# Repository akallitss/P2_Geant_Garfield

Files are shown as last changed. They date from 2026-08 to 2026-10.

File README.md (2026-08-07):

# P2 Micromegas Simulation

Geant4 simulation of the P2 wedge Micromegas detector (MESA / Mainz).

> **Read [`docs/HANDOFF.md`](docs/HANDOFF.md) first.**
>
> **Running it on lxplus: [`docs/RUNBOOK.md`](docs/RUNBOOK.md)** — including
> what is *not* yet runnable (Stage B does not exist, there is no pillar
> code, and HTCondor submission does not speak `p2` mode).
>
> **Update 2026-08-06: VMM analysis re-scoped for a *pad* detector, and a
> first time-resolution prediction exists.** The charge cloud fires **~1.1
> pads on average**, so inter-pad clustering is a ~10 % minority effect;
> **VMM neighbor logic** — a strip-detector feature — reads *chip-channel*
> neighbors, which on this pad plane are physical neighbors only 74 % of the
> time in one mapping revision and **7.7 %** in the other (median partner
> distance 12 mm vs **126 mm**). Baseline is therefore **NL off**, with
> clustering done offline on geometric adjacency
> ([`vmm/nl_map.py`](vmm/nl_map.py)). Separately, we now predict a per-pad
> time resolution of **≈ 10–13 ns (Ar mixes) / 15–25 ns (Ne mixes)**,
> dominated entirely by primary-ionization statistics — the number to compare
> against the SPS run
> ([`docs/research/TIME_RESOLUTION_NOTES.md`](docs/research/TIME_RESOLUTION_NOTES.md),
> [`vmm/time_resolution.py`](vmm/time_resolution.py)). Also corrected: the
> "two mapping revisions disagree on 79/1280 pads" claim was a rounding
> artifact — the pad planes are identical to 2.5 µm; the revisions disagree
> on the **readout order** (11/1280 channels agree), which is what matters.
>
> **Update 2026-08-05 (night): it builds and runs.** First working P2
> simulation on lxplus — geometry passes overlap checks, and three bugs were
> fixed getting there (two fatal: self-intersecting `WedgeOutline` polygons
> that killed `G4ExtrudedSolid`, and a ROOT thread-safety race that
> core-dumped every multi-threaded run). Output now carries **full
> provenance**: every gas cluster knows the process, layer, position and
> energy of the interaction that started its chain, and every volume that
> receives energy is scored. The **P0.1 gas-composition bug is fixed** too (volume-vs-mass
> fractions *and* STP-vs-20 °C densities — see
> [`docs/research/GAS_FIX_NOTES.md`](docs/research/GAS_FIX_NOTES.md)).
> First physics, measured with the corrected gas: **90 % of photon-induced
> gas signals originate in the mesh and the copper pad plane**, not in the
> gas, and switching argon → neon removes only **(12 ± 3) %** of them —
> confirming the analysis below. Speed and
> campaign cost: [`docs/BENCHMARKS.md`](docs/BENCHMARKS.md). Biggest
> remaining unknown: [`docs/NEEDED_INPUTS.md`](docs/NEEDED_INPUTS.md).
>
> **Update 2026-08-05 (late): the gas premise changed.** The expected photon
> background is **50–100 keV** (plus a harder tail), well above the Ar
> K-edge. An analytic pass
> ([`docs/research/PHOTON_DISCRIMINATION_NOTES.md`](docs/research/PHOTON_DISCRIMINATION_NOTES.md),
> reproducible via `python3 scripts/photon_budget.py`) finds that (a) Ar vs
> Ne interaction probability differs by only 5.4×→2.1× across the band, and
> (b) **conversions in the mesh and copper pad plane outnumber gas
> conversions by 15–65×**, a gas-independent floor. Net: Ar/Iso and Ne/Iso
> total fake sources differ by under 10 %, while neon costs a 30× worse
> zero-cluster floor — so **argon is now a co-baseline, not the incumbent to
> beat**. The **energy-deposition discrimination** handle (MIP Landau vs
> Compton/photoelectric deposits) is real at 3–30× MIP but its target is the
> minority population. Campaign plan amended throughout; new Phase-0 items
> P0.12 (per-event interaction classification), P0.13 (mesh cross-check)
> and a γ-production-cut bug suppressing Cu-K fluorescence — **all three
> now implemented and verified, see the update above.**
>
> **Update 2026-08-05 (evening):** the simulation **campaign is now planned**
> — [`docs/SIM_CAMPAIGN_PLAN.md`](docs/SIM_CAMPAIGN_PLAN.md) is the working
> document (phases, run matrices, gas candidate list, chain architecture),
> backed by two sourced research notes in
> [`docs/research/`](docs/research/). The **VMM3a electronics emulator is
> implemented and unit-tested** in [`vmm/`](vmm/README.md). Execution is
> **gated on Alexandra's geometry review**; the plan's Phase 0 lists prep
> tasks that are safe now — first among them the **gas-mixture
> mass/volume-fraction bug fix (P0.1)**, which must land before any Ar-vs-Ne
> comparison.
>
> **Update 2026-08-05:** the P2 wedge geometry is now implemented as a new
> `p2` mode (the default) — full stack in gerber coordinates: readout PCB
> (18 µm Cu / 200 µm FR4 / 18 µm Cu), amp gap, woven mesh (48/19 µm, as an
> effective-density slab), drift gap, two-foil drift cathode (1 mm apart, Al
> on the gas side), gas frame, carbon back frame (1 mm) and mylar sheets with
> the overpressure bulge of the outer two modelled as terraced domes.
> **Several dimensions are still educated guesses —
> [`docs/P2_MODEL.md`](docs/P2_MODEL.md) is the list of what is measured vs.
> assumed and what to confirm.** Not yet compiled or validated on lxplus.
> The other modes are inherited MX17 and untouched.

## Layout

| Path | What |
|---|---|
| `mm_sim.cc`, `src/`, `include/` | Geant4 application — `p2` mode (default) + inherited MX17 modes |
| `scripts/model/` | Python mirror of the P2 geometry + figure generation |
| `docs/SIM_CAMPAIGN_PLAN.md` | **THE campaign plan**: phases P0–4, run matrices, gas list, chain architecture, bookkeeping |
| `docs/research/` | sourced research notes: `TOOLCHAIN_NOTES.md` (Geant4/Garfield++/Magboltz/Heed/VMM), `GAS_NOTES.md` (Ne mixtures, flammability, procurement), **`PHOTON_DISCRIMINATION_NOTES.md` (50–100 keV cross-sections, edep discrimination, wall-conversion floor, edep→ADC proportionality)**, `TIMING_PSD_NOTES.md` (time-structure handle), **`TIME_RESOLUTION_NOTES.md` (predicted σ_t per pad, contribution budget, SPS comparison protocol)** |
| `scripts/photon_budget.py` | analytic photon-interaction budget — the numbers the Geant4 photon runs must reproduce |
| `docs/NEEDED_INPUTS.md` | **register of what we are guessing** — spatial/angular distributions, spectra, geometry, noise |
| `docs/BENCHMARKS.md` | measured speed on lxplus + campaign cost estimate |
| `docs/OUTPUT_FORMAT.md` | ROOT/CSV schema: EventTree, ClusterTree provenance, VolumeTree |
| `vmm/` | **VMM3a electronics emulator** (Athena shaper port + pad digitizer, unit-tested), **pad/channel adjacency map (`nl_map.py`)** and the **time-resolution toy (`time_resolution.py`)** — see `vmm/README.md` |
| `docs/P2_MODEL.md` | **as-built model, assumptions, open questions** |
| `docs/P2_EXPERIMENT.md` | P2@MESA / BASKET physics context, kinematics, rates (sourced) |
| `docs/SIM_CAMPAIGN_BRIEF.md` | campaign handoff snapshot (capabilities/assumptions; plan now in SIM_CAMPAIGN_PLAN.md) |
| `macros/`, `scripts/`, `ls_calibration/`, `sr90_calibration/` | build, HTCondor submission and analysis, inherited from MX17 |
| `design/` | P2 fabrication data: gerbers, drill, bulk masks, channel mapping, drift frame — see [`design/README.md`](design/README.md) |
| `scripts/gerber/` | gerber parsing and geometry extraction tools |
| `docs/P2_GEOMETRY.md` | **every P2 dimension, with its source** |
| `docs/HANDOFF.md` | state of play, plan, and open questions |
| `docs/MX17_README.md` | the original MX17 README (modes, CLI, output format) |

## The detector in one table

Measured from the fabrication files (see `docs/P2_GEOMETRY.md`):

| | |
|---|---|
| Shape | 60° annular sector, apex on the beam axis |
| Board | r = 95 → 650 mm, radial edges offset +10 mm, top cut at y = 540 mm |
| Active area | r = 120 → 590 mm, φ = 0.97° → 59.0°, ≈ 1689 cm² |
| Readout | 1280 pads = 10 connectors × 128 ch; 42 rings, 11.43 mm radial pitch |
| Pad cell | ≈ 11.43 × 11.86 mm (area-equalized) |
| Pillars | Ø0.5 mm on a 2.000 mm pitch, 41 366 of them |
| Readout PCB | 2-layer, 0.236 mm (18 µm Cu / 200 µm FR4 / 18 µm Cu) |
| Drift gap | 3 mm confirmed baseline (campaign scans 1–4 mm; two frame variants exist) |

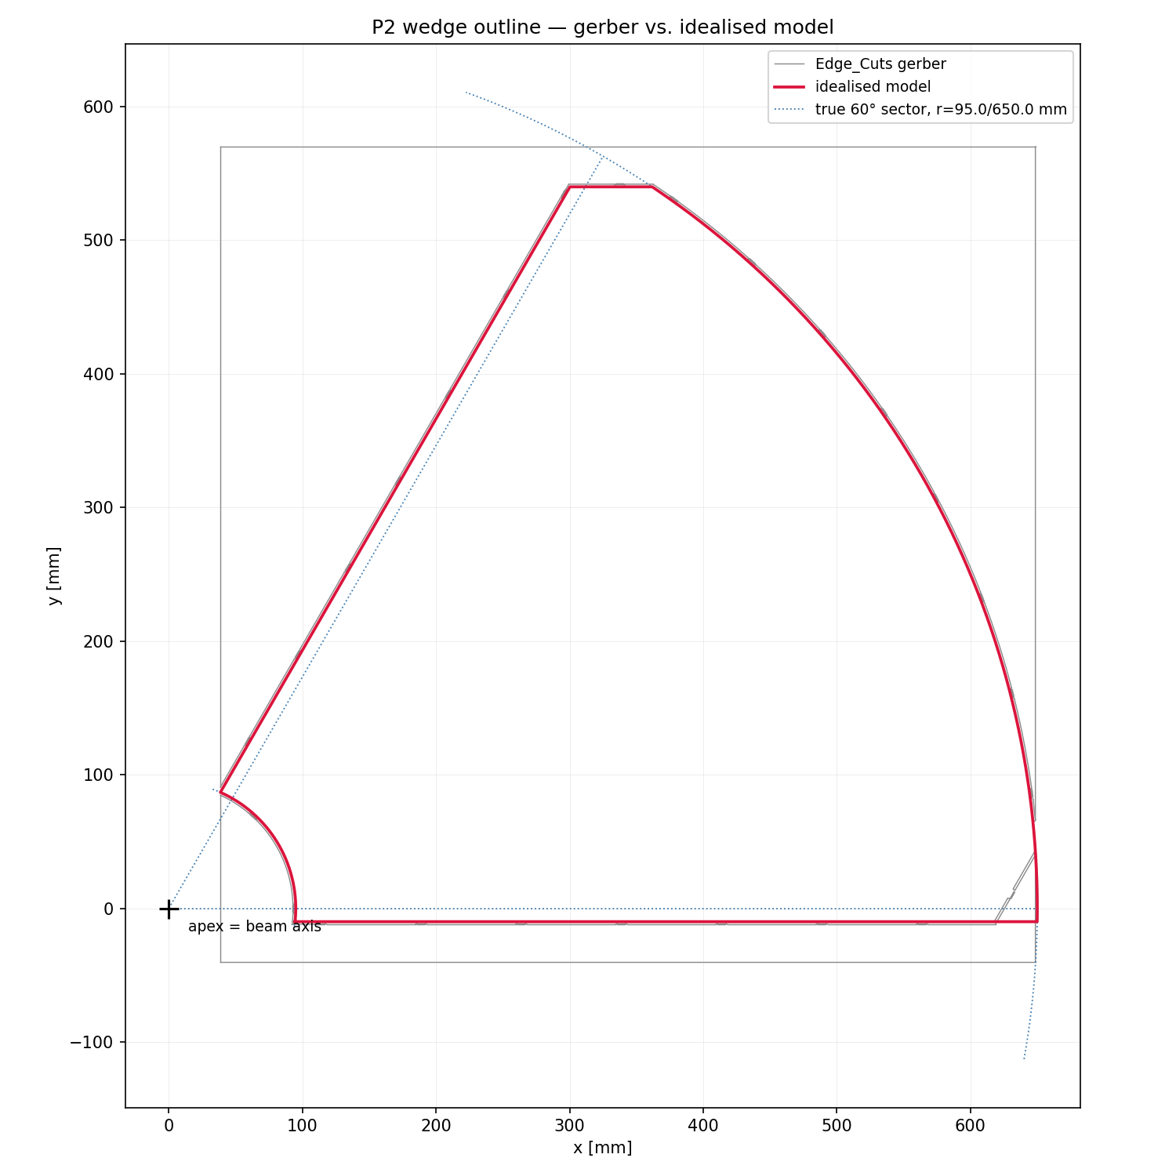
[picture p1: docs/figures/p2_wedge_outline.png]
P2 wedge outline


## Running the P2 simulation

```bash
./build/mm_sim -n 10000                     # p2 mode, ArIso, 155 MeV e-, aimed mid-wedge
./build/mm_sim --drift-gap 4 -g ArCO2       # 4 mm frame variant, different gas
./build/mm_sim --gun-x 150 --gun-y 30       # aim near the inner radius
python scripts/model/plot_p2_model.py       # geometry figures -> docs/figures/
```

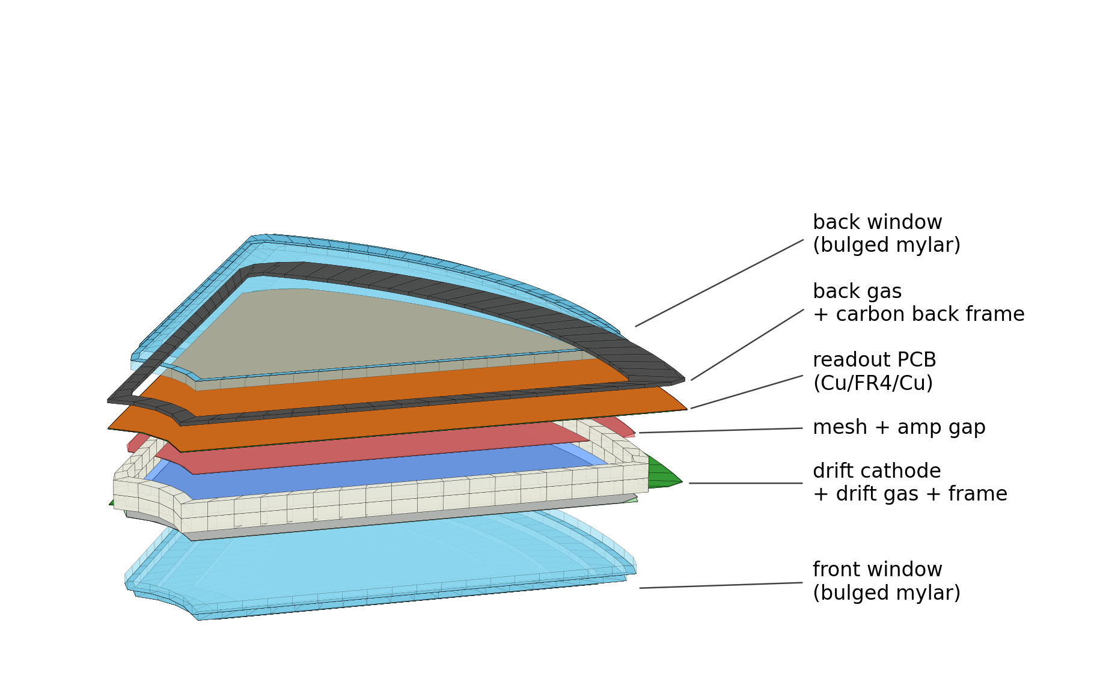
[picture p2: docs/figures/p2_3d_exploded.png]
exploded model


## Gerber tools

```bash
# wedge outline parameters + comparison figure against the gerber
python scripts/gerber/p2_wedge_model.py --out wedge.png

# readout pad map (also cross-checks the two mapping revisions)
python scripts/gerber/analyze_p2_readout.py --plot padmap.png

# full geometry dump for any gerber set
python scripts/gerber/analyze_p2_geometry.py
python scripts/gerber/analyze_p2_geometry.py --dir design/gerbers/RKP2_10x10/Gerber
```

`scripts/gerber/gerber_outline.py` is a small standalone RS-274X reader (no
external gerber library needed); the analysis scripts need numpy and matplotlib.

## Building (inherited from MX17, unchanged)

```bash
source scripts/setup_lxplus.sh   # Geant4 11.2 + ROOT 6.30 from CVMFS
bash scripts/build.sh            # -> build/mm_sim
```

The command-line interface, simulation modes and output format are documented in
[`docs/MX17_README.md`](docs/MX17_README.md) and still apply to the code as it
stands.

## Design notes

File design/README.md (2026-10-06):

# P2 detector design data

Copied 2026-08-05 from
`/media/dylan/LaCie/Extras/Physics/Post-Doc-Saclay/P2-detector-design/`.
Dates below are the ones written *inside* the files, which do not always match
the directory names on the drive (`Version-Nov-25` holds March 2024 output;
`Version_Apr26` holds both January and May 2026 output).

Measurements taken from these files are in [`../docs/P2_GEOMETRY.md`](../docs/P2_GEOMETRY.md).

## `gerbers/P2_BASKET_Apr26/` — current production readout ★

KiCad 9.0.2, generated 2026-01-20, project `P2_BASKET`.
From `wedge_det_design/Version_Apr26/FABRICATION_P2/`.

```
Gerber/     F_Cu, B_Cu, Edge_Cuts, F_ENIG_Finition, User_Drawings
NCDrill/    P2_BASKET.drl + drl_map (dxf, pdf)
Artworks/   per-layer PDFs
Stack_Up_P2.txt    2-layer: 18 µm Cu / 200 µm FR4 core / 18 µm Cu
TOP.jpg BOT.jpg    photos of the finished board
```

This is the primary geometry source. `Edge_Cuts.gbr` also contains the 610 × 610
mm fabrication panel and the 2 mm routing channel — neither is part of the
detector.

## `gerbers/bulk_masks_CERN/` — bulk Micromegas masks ★

Ucamco UcamX, 2026-05-13. From `wedge_det_design/Version_Apr26/Bulk_CERN/`.

`P2_Mask1.gbr` / `P2_Mask2.gbr` (+ PDFs) are the CERN bulk soldermask / pillar
masks. `P2_Mask2` carries the 41 366 pillars and therefore defines the active
area. `3717-A-Alexandra Kallitsopoulou - P2 Micromegas bulk.pdf` is the bulk
run request.

`older_revisions/` is misnamed: it holds the **Saclay insulation masks**
`P2_BASKET-Mask_M1/M2_V1|V2.gbr` (KiCad, 2026-03-24), byte-identical to
`Detector_Drawings/Version_Apr26/Insulation_masks/`. **`M2_V1` is the pillar
mask det1–det4 were bulked with** (12 477 × Ø0.8 mm + 5 × Ø6.15 mm; confirmed
in P2_basket_analysis 2026-09-14) and is the simulation's default pillar set;
V2 has ~800 fewer pillars towards the fan edges. M1 carries only alignment
marks and the outline. The CERN `P2_Mask2` above is det5's pattern.

## `gerbers/DummySector0_Nov25/` — earlier wedge

KiCad 7.0.7, dated 2024-03-26, rev 0.30. From
`wedge_det_design/Version-Nov-25/GERBERS/`. F_Cu, B_Cu, Edge_Cuts,
User_Drawings, drill and a `.gbrjob`. Kept for diffing against the current
design; not the production geometry.

## `gerbers/RKP2_10x10/` — prototype readout

KiCad 6.0.1, 2022-10-21. From `10x10-design/RKP2/`. Gerbers, both drill files
and the `.kicad_pcb`. Relevant only if a small-prototype simulation is wanted.

Despite the `10x10-design` directory name, `Edge_Cuts` is a 300 × 300 mm square
centred on the origin; the copper only covers ~256 × 256 mm of it. The "10×10"
presumably refers to the active area, which was not separated out here.

## `gerbers/K59V_Fx2Mec8/` — interconnect board

KiCad 8.0.0, 2024-05-02. From `wedge_det_design/K59V/_ EXPORT/`. 14 gerber
layers (including 4 inner signal/GND layers), NCDrill and the BOM. Sits off the
active area — material budget only.

Left on the LaCie drive: the KiCad project and schematic, the DXF exports, the
12.7 MB `Fx2Mec8.step`, six dated backup zips, the Würth manufacturer copy, and
the Hirose FX20-140 / Samtec MEC8 vendor 3D models.

## `mapping/` — channel mapping

From `wedge_det_design/Maarten-Irakli-mapping/`. Two revisions of the same
1280-pad map:

- `connector_0..9.txt` — 7 columns, has `AbsIndex`, ordered outer radius inward
- `Mapping/connector_0..9.txt` — 9 columns, adds `X`, `Y`, `PadName`, ordered
  inner radius outward, plus `MappingFx2Mec.xlsx`

They describe the **same pad plane** — matched by nearest neighbour, all 1280
pads agree to 2.5 µm (print precision). *(An earlier note here said "1201 of
1280 agree"; that came from comparing coordinates rounded to 0.01 mm and was
an artifact — fixed in `scripts/gerber/analyze_p2_readout.py` on 2026-08-06.)*

What they genuinely disagree on is the **channel assignment**: only
**11 of 1280 (connector, channel) pairs land on the same pad**. Geometric
pad-level work is therefore safe with either file; anything per-channel is
not — VMM neighbour logic, dead-channel masks, per-channel test-beam
comparisons. **Which one the DAQ uses is an open question** — see the
handoff, and `vmm/nl_map.py` for what it changes (chan ±1 is a 12 mm
neighbour in one revision and a 126 mm one in the other).

`README` (French) documents the index conventions. `module_equalized.gbr` is a
non-CAD gerber of raw draw commands in mm that goes with the mapping, with a
`.png` preview.

> `Phi` and `DeltaPhi` in these files are in **radians**, not degrees.

## `mechanical/` — drift frame

From `DRIFT_P2_261124/DRIFT_P2_261124/`.

- `P2_Frame_V1_3mm.stp` — 3 mm drift variant
- `P2_Frame_V2_4mm.stp` — 4 mm drift variant

The matching `.stl` meshes (~280 MB each, very finely tessellated) were left on
the drive.

## `docs/`

`FX20-60P-0.5SV15...pdf` (Hirose connector catalog) and `MariamInventaire_P2.pptx`.

## Not copied

`detectors-labo-bulk-info/` on the drive holds no design files — it is bulk
fabrication travelers (Excel *Fiche de préparation* sheets for mesh and bulk
runs, 2024–2025).

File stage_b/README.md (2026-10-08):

# Stage B — ionization clusters → per-pad charge and time

**Status (2026-10-08): runs end to end with Magboltz gas transport.** It runs
on real Stage A output and produces per-pad charge and arrival time. The gas
transport is now Magboltz; the gain, induced current, pillars and mesh
transparency are still placeholders, all listed below and all recorded in
every output file. **Do not quote a number from this stage without reading §3.**

```bash
python3 -m stage_b.selftest                       # 23 checks, no Geant4 needed
python3 -m stage_b.run stageA.root -o padhits.root
```

## 1. What it does

```
ClusterTree (Stage A)
  └─ depth from the drift frame        RunMeta.meshZ_mm − z_world
      ├─ attachment                    exp(−depth/λ)
      ├─ drift time                    depth / v_d
      ├─ longitudinal diffusion        N(0, σ_L √depth / v_d)   on time
      ├─ transverse diffusion          N(0, σ_T √depth)         on x, y
      ├─ mesh transparency             Bernoulli(ε)
      ├─ Polya gain                    Γ(θ+1, G/(θ+1))
      └─ pad lookup                    (x,y) → pad, polar
  └─ sum charge / earliest time per (event, pad)  →  PadHitTree
```

| module | role |
|---|---|
| `frame.py` | the drift frame, read from Stage A's `RunMeta` |
| `gas.py` | transport parameters; `TransportTable` is the Magboltz drop-in point |
| `padplane.py` | point → pad, built from `design/mapping/` |
| `clusters.py` | Stage A `ClusterTree` reader |
| `digitize.py` | the chain above |
| `run.py` | CLI; writes `PadHitTree` + `StageBMeta` |
| `selftest.py` | closed-form checks with synthetic clusters |

## 2. First result

400 muon events, Ar/iso, 3 mm, gain 10⁴, `--beam-spread 11.43`:

- **1.070 pads per event** (373 single / 26 double / 1 triple)
- median pad charge **37.6 fC**
- drift-time span **0–60 ns**, matching the 60 ns placeholder for Ar/iso

The pad multiplicity is the interesting one. **~1.1 pads/hit was previously
derived from a separate geometric analysis** (`vmm/nl_map.py`,
`SIM_CAMPAIGN_PLAN.md` §2); the full Geant4 → transport → pad chain now
reproduces it independently. That figure is what the "neighbour logic off"
baseline rests on, so having two independent routes to it matters.

## 3. Placeholders — what is not yet real

In rough order of how much each could move an answer.

1. **Gas transport: Magboltz since 2026-10-08 (P0.10).** `v_d`, σ_L, σ_T and
   attachment now come from dry Magboltz tables for the six gases of the
   October 2026 campaign (Ar/iso 95/5, 90/10, Ne/iso 95/5, 85/15,
   Ar/CO₂/iso 93/5/2, Ar/CF₄/iso 88/10/2), interpolated at `--drift-field`
   (default 625 V/cm, the SPS July 2026 point). Tables:
   `gas_tables/magboltz_dry_20261008.json`, made by
   `scripts/garfield/make_gas_table.C` + `export_gas_json.C`.
   `--transport placeholder` keeps the old values for comparison.
   *The real detector still drifts slower than a dry table:*
   MX17's bench finds **water contamination dominates v_d** (36.6 µm/ns
   measured vs a much higher dry prediction, 1–2 % H₂O inferred at SPS).
   `--v-scale` exists so a run states which assumption it was made under
   rather than hiding a preference in a constant.
   The **gain** is still a configured mean + Polya spread: the Townsend
   coefficients are in the table, but without Penning transfer they give a
   gain far below the measured one, so it must be calibrated on the SPS HV
   scans first.

2. **Induced current is not modelled (P0.17).** Each electron contributes its
   charge as a delta at its arrival time. The real signal is a fast electron
   spike plus a ~150 ns ion tail, and that shape sets the leading edge. This
   is the main model risk in the σ_t prediction, and it is cheap to fix for
   our non-resistive stack (static Ramo, Riegler closed form, already in
   Garfield++ `ComponentParallelPlate`).

3. **No pillars (P0.16).** They are not in the Geant4 geometry either, so
   electrons that should land on a pillar and be lost are amplified normally.
   Biases efficiency high by roughly the pillar area fraction, **~4.8 %**.

4. **Mesh transparency is a constant (P0.13).** Not a field map. Default 1.0,
   i.e. off; set `--mesh-transparency` explicitly if you want it.

Also absent by design, because Stage C owns them: shaping, threshold, ENC,
PDO/TDO. Use `vmm/` for those.

## 4. Traps

**World z is not drift depth.** The drift gas sits at positive world z and
electrons drift toward **+z**, so treating a cluster's z as "distance
drifted" is wrong by an offset *and* a sign — and stays finite and plausible
while being wrong. Stage A therefore records the frame
(`RunMeta.meshZ_mm` and friends) and `frame.py` converts. Never hardcode a z:
the drift gap is a scan axis. MX17 hit this and had half their gap at
negative depth.

**`nPrimary`, not `edep/W`.** Stage A already applied W and carried the
sub-W remainder probabilistically. Re-deriving would double-count.

**AmpGas clusters are not drift clusters.** They are already past the mesh,
so they skip the drift and are amplified over only the remaining gap:
`G^((gap−d)/gap)`. The gain spans ~4 decades across that one 150 µm volume.

**A pencil-beam Stage A file cannot give you pad multiplicity.** With
`beamSpread_mm = 0` every event lands on the same point, so the answer
describes that point, not the pad cell. `run.py` prints a NOTE when it sees
one. Stage A's default aim point is a pad centre in both polar coordinates —
which took two attempts, because fixing the radial coordinate put it in an
azimuthal gap.

**Mapping revision.** Pad *positions* are revision-independent (identical to
2.5 µm), so the geometry here is safe. Anything channel-level is not: the two
revisions agree on 11/1280 channel assignments. The revision used is recorded
in `StageBMeta`.

**Pad geometry source.** `padplane.py` reads `design/mapping/`, whose ring
radii sit 65–81 µm outside the gerber-derived pad mid-radii in
`include/P2PadMap.hh` (0.6 % of a pad). Irrelevant except within ~80 µm of an
edge; worth unifying on the gerber table when someone touches this next.

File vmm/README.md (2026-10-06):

# VMM3a emulation — Stage C of the simulation chain

**Written:** 2026-08-05. **Updated 2026-08-06** (neighbor logic re-scoped for
a *pad* detector; time resolution promoted to a first-class deliverable).
Status: **model implemented and unit-tested; not yet connected to Stage B
(which doesn't exist yet) — no physics run.**
Campaign context: `../docs/SIM_CAMPAIGN_PLAN.md` §2 (chain architecture),
§5 (ADC discrimination study). Toolchain citations:
`../docs/research/TOOLCHAIN_NOTES.md` §6. Timing study:
`../docs/research/TIME_RESOLUTION_NOTES.md`.

## 1. Purpose

Emulate the VMM3a front-end response per pad so the campaign can apply a
*realistic* hit threshold ("final ADC cut") when computing electron
efficiency vs photon rejection, and so we can predict the **time resolution**
we should see at the SPS. What matters for that, in order:
(1) the charge threshold in physical units with a defensible noise floor,
(2) **per-pad timing** — the TDO width, its contribution budget, and the
coincidence window it implies (`time_resolution.py`);
(3) the ballistic deficit if a short peaking time is used;
(4) ADC saturation (interacts with the photon charge spectrum at high gas
gain);
(5) neighbor logic — **demoted 2026-08-06** (see §3.1: the charge cloud fires
~1.1 pads, and on this pad plane NL does not read the physical neighborhood
anyway; baseline is NL **off**).

> **Detector fact that drives most of this (Dylan, 2026-08-06):** the charge
> cloud fires **~1.1 pads on average**. Inter-pad clustering is a ~10 %
> minority effect — real, worth using optimally, but not a design driver.
> Everything below that assumes a strip-like multi-channel cluster (neighbor
> logic, µTPC, charge interpolation, cluster-size cuts) has to be re-derived
> for that regime rather than inherited from ATLAS NSW.

## 2. What is implemented here

| file | content |
|---|---|
| `vmm_shaper.py` | Python port of the ATLAS Athena closed-form VMM shaper (`reference/VMM_Shaper.cxx`): h(t), first-peak finding, threshold-crossing time, ballistic-deficit scaling. Self-test: `python3 vmm_shaper.py`. |
| `vmm_emulator.py` | Channel emulator: `VMMConfig` (operating point), `PadDigitizer` with tiers **T0** (charge-sum + threshold) and **T1** (shaper peak + NL + time window + ENC noise + ADC quantization/saturation). Smoke test: `python3 vmm_emulator.py`. |
| `nl_map.py` *(new 2026-08-06)* | Pad map with **both** adjacency relations: `channel_neighbors()` (what VMM NL actually reads: chan ±1) and `geometric_neighbors()` (physically touching pads, for offline clustering). Prints the mismatch report of §3.1: `python3 nl_map.py`. |
| `time_resolution.py` *(new 2026-08-06)* | Standalone toy MC for the per-pad TDO width — clusters → drift → Polya → shaper → threshold crossing → ENC jitter → TAC quantization, with a contribution breakdown. Needs no Geant4 and no Stage B: `python3 time_resolution.py --breakdown`. Results and interpretation: `../docs/research/TIME_RESOLUTION_NOTES.md`. |
| `reference/` | verbatim Athena sources (provenance + license in `reference/PROVENANCE.md`) — the ground truth for the port. |

Validated numerically: for a single electron of charge Q, the shaped peak
amplitude equals Q (t_peak ≥ 150 ns) or Q·t_peak/150 ns below — i.e. the
Athena normalization constant 1/0.411819 makes "amplitude" directly a
charge, so **thresholds are in electrons/fC, no mV conversion needed**
until the ADC model is switched on.

## 3. The shaper model (from Athena, constants by G. Iakovidis)

Per electron of charge Q arriving at t₀ (t_peak in ns, a = t_peak/1.5):

```
h(t) = Q · (1/0.411819) · s_bd · a³p₀|p₁|² ·
       [ K₀ e^(−p₀Δt) + 2|K₁| e^(−Re p₁ Δt) cos(−Im p₁ Δt + arg K₁) ]
K₀ = 1.584   K₁ = −0.792 − 0.115i   p₀ = 1.263/a   p₁ = (1.149 − 0.786i)/a
s_bd = min(1, t_peak/150 ns)        (Micromegas ion-tail ballistic deficit)
```

The same transfer function is written up in
`../data/VMM-electronics/2026_Iakovidis_et_al_VMM_shaper_from_Patrick_Scholer.pdf`
(Alexopoulos, de Geronimo, Iakovidis, Polychronakos; received 2026-10-06).
Its poles, residues and a = t_peak/1.5 match the constants above, checked:
peak at 98.9 ns for t_peak = 100 and 197.8 ns for 200.
- The note's text gives Im p₁ = −0.789. Its own code uses −0.786, and only
  −0.786 reproduces its K₀ = 1/((p₀ − Re p₁)² + Im p₁²) = 1.584 (−0.789 gives
  1.574). We keep −0.786.
- The note has **no ballistic-deficit term**: s_bd comes from Athena
  (`MM_ElectronicsResponseSimulation`, 150 ns ion tail tuned on ATLAS NSW
  128 µm gaps, Ar/CO₂). For our 150 µm gap and Ne mixtures that 150 ns is an
  assumption. It is the term that sets the 100 ns vs 200 ns amplitude ratio,
  and the Garfield signal check should fix it.

Channel logic (Athena `MM_ElectronicsResponseSimulation`):
- a channel **fires** if the shaped signal crosses its threshold inside the
  search window (acceptance window extended by `vmmDeadtime` = 200 ns below
  and `vmmUpperGrazeWindow` = 150 ns above);
- with **neighbor logic** on, channels adjacent to a fired one are read out
  too, re-evaluated with threshold ≈ 1 e⁻ (their recorded time still comes
  from their own — tiny — threshold crossing);
- recorded per digit: first-peak amplitude (PDO proxy) and
  threshold-crossing time (TDO proxy); digits outside the time window are
  dropped.

### 3.1 Neighbor logic on a *pad* detector — re-scoped 2026-08-06

Neighbor logic is a **strip-detector feature**. On a strip chamber, chip
channel *n±1* is also the strip physically next door, so NL recovers the
sub-threshold shoulders of a charge cluster that genuinely spans several
strips. Two things break that here.

**(a) The cluster is one pad.** The charge cloud fires ~1.1 pads on average,
so ~90 % of hits have nothing to recover; the recoverable population is the
~10 % of tracks landing near a pad edge, and on those the partner pad carries
by construction the smaller share of the charge.

**(b) Channel neighbors are not spatial neighbors.** NL acts on chip-channel
number. The P2 pad → connector-pin assignment snakes through the pad plane,
so chan ±1 is a physical neighbor only sometimes — and *how* often depends on
which mapping revision the DAQ uses. Measured with `nl_map.py` over all
1280 pads:

| | rev A (`connector_*.txt`) | rev B (`Mapping/connector_*.txt`) |
|---|---|---|
| NL partner physically touching | **7.7 %** | **73.8 %** |
| median NL-partner distance | **126 mm** | **11.9 mm** |
| 90th pct / max distance | 297 / 457 mm | 38 / 54 mm |
| fraction of the 5.78 real neighbors NL reads | **3 %** | **25 %** |
| pads whose NL set contains no real neighbor | 88.8 % | 0 % |
| non-neighbor channels forced per fired pad | 1.83 | 0.52 |
| **P(the charge-sharing partner is in the NL set)** | **2 %** | **36 %** |

Read the last row as the useful yield: even in the favourable revision, NL
catches the sharing partner about a third of the time, because chan ±1 can
cover at most 2 of the 4 pad edges (per-pad range 8–51 %). In rev A, NL is
essentially a random-pad readout — chan ±1 sits a median 126 mm away, i.e.
NL would triple the data volume while reading pads on the other side of the
wedge. **This is not a problem, it is a fact about the mapping** — but it
means NL cannot be modeled as "geometric neighbors", and `nl_map.py`
therefore exposes the two relations separately.

Consequences, adopted as the campaign baseline:

1. **Baseline: NL off.** P2 does not currently plan to read out neighbors
   (Dylan, 2026-08-06: probably not, unless we find an advantage). The
   emulator default is now `neighbor_logic=False`; NL-on is a scan variant.
   The upside it could buy is bounded above by ~10 % of tracks × 36 %
   coverage ≈ **3–4 % of tracks gaining a partial second pad**, against a
   ~3× channel-occupancy/bandwidth cost — that is the trade to quantify in
   Phase 2, and the number NL has to beat.
2. **Clustering is an offline, geometric step, and it is independent of NL.**
   Pads that each pass threshold get merged using `geometric_neighbors()`.
   That is where the small inter-pad clustering that does exist is used, and
   it works with NL off. Never pass geometric neighbors to the NL model:
   that simulates a detector we do not have.
3. **If NL is ever enabled, it must be simulated in channel space** via
   `PadMap.channel_neighbors()`, with the revision stated — otherwise
   cluster-size and occupancy predictions are wrong in both directions
   (missing the far-away forced channels, inventing the near ones).
4. **Whether NL crosses the 64-channel chip boundary** changes only 20 of
   2540 pairs (0.8 %) — irrelevant at our multiplicity, so this NEEDS-DATA
   item can be closed as "does not matter".

ATLAS defaults worth knowing (from `MM_DigitizationTool.h`, for orientation
— **not** P2 settings): global threshold 15 000 e⁻, or strip-noise-scaled
threshold ×7 (`useThresholdScaling`, their default); avalanche gain 6×10³
(Ar/CO₂ 93:7); NL **off** in ATLAS production sim; strip/ART dead time
200 ns; capacitive cross-talk to 1st/2nd strip neighbor 0.3/0.09 (strip
chambers — pad cross-talk for P2 unknown, see §7).

## 4. VMM3a chip facts (verified against the papers, `docs/research/TOOLCHAIN_NOTES.md` §6)

| parameter | value |
|---|---|
| channels / package | 64, BGA 21×21 mm² |
| shaper | 3rd-order DDF (1 real + complex-conjugate pole pair) |
| peaking time | 25 / 50 / 100 / 200 ns |
| gain | 0.5 / 1 / 3 / 4.5 / 6 / 9 / 12 / 16 mV/fC |
| threshold | global 10-bit DAC + per-channel 5-bit trim |
| outputs | 10-bit PDO (peak), 8-bit TDO (TAC: 60/100/350/650 ns ramps), 6-bit fast ADC |
| conversion / rate | ~250 ns; dead-timeless to ~4 MHz/ch (continuous mode) |
| neighbor logic | forces readout of channel-number neighbors of a triggered channel; crosses chip boundaries via bidirectional IOs (**≠ spatial neighbors here** — §3.1) |
| TDO timestamp | threshold-crossing time **or** time-at-peak, per-chip config — matters for the timing comparison (§5) |
| VMM3a extras | two-stage (mild/strong) ion-tail suppression |
| BASKET usage (P2_EXPERIMENT.md) | expected signal ~21 fC; range 62 fC–2 pC quoted; pad capacitance 75–170 pF |

Noise: the VMM3a paper (JPCS 1498 (2020) 012051, Fig. 5) shows measured ENC
of a few ×10³ e⁻ on a small MM prototype (~10 pF) as a function of gain,
and notes the DDF design targets input capacitance "much smaller than
200 pF". **No published ENC curve covers the P2 pad capacitance range
(75–170 pF) at our gain/peaking settings** — see §7.

## 5. Time resolution *(new 2026-08-06)*

Timing is now a first-class deliverable, not a Phase-4 afterthought: we want
a number to compare against the SPS run. Full write-up, contribution budget
and test-beam asks: **`../docs/research/TIME_RESOLUTION_NOTES.md`**. The
short version, from `time_resolution.py` (3 mm, gain 10⁴, 2 fC, ENC 3 k e⁻,
threshold-crossing timestamp, walk-corrected with the hit's own PDO):

| gas | σ_t @ t_p = 100 ns |
|---|---|
| Ar/iC₄H₁₀ 95/5 | 10.6 ns |
| Ar/CO₂/iC₄H₁₀ 93/5/2 | 12.1 ns |
| Ne/iC₄H₁₀ 90/10 | 15.0 ns |
| Ne/CH₄ 93/7 | 16.2 ns |
| Ne/CO₂/iC₄H₁₀ 95/3/2 | 25.0 ns |

**It is a gas measurement, not an electronics measurement**: σ_t ≈
(1.0–1.5)/(n_p·v_d), i.e. the arrival spread of the first primary clusters.
ENC jitter, TAC quantization, Polya and diffusion together contribute < 3 ns
in quadrature. Time-walk correction using the streamed (PDO, TDO) pair is
worth ~30 % and must be stated on both sides of any comparison. Note that
**µTPC is not available to us** — at ~1.1 pads per hit there is one timestamp
per hit, so gas, threshold and peaking time are the only knobs.

Emulator-side consequence: T1 already returns `time_ns`; what is still
missing is TDO quantization and the peak-vs-threshold timestamp mode (§8
item 3), both cheap and now worth doing.

## 6. How Stage B connects (interface contract)

Input to `PadDigitizer.digitize()` — one event:

```python
{pad_id: (arrival_times_ns, charges_electrons)}   # per-pad electron lists
```

produced by the Stage B sampler as: for each Geant4/Heed primary electron —
drift time (z/v_d + longitudinal diffusion) → mesh transparency survival →
Polya gain draw → pad assignment (transverse diffusion + pad map). The
avalanche charge arrives as one entry per primary electron (the ~ns
avalanche development is far below shaper time scales).

Output: `PadHit(pad, charge_electrons, time_ns, above_threshold, saturated)`
— feed directly to the ROC/efficiency analysis. `above_threshold=False`
marks NL-only reads (keep them separable: the topology cut may or may not
use them; with the NL-off baseline they simply do not occur).

Recommended campaign scan knobs: `threshold_electrons` (the headline axis,
scan ~5–60 k e⁻ ≈ 1–10 fC), `peak_time_ns` ∈ {50, 100, 200} (100 ns is the
timing optimum at no efficiency cost — §5), `enc_electrons` ∈ {0, measured};
NL **off** by default, on only as an explicit variant with a *channel*
neighbor map — everything else frozen per run.

Downstream of the digitizer, clustering merges hit pads using
`nl_map.PadMap.geometric_neighbors` — independent of the NL setting, and the
place where the ~10 % of hits that do share charge get used.

## 7. Open items (NEEDS-DATA — ask BASKET/Saclay; none block coding)

1. **Operating point**: which gain (mV/fC), peaking time, and threshold-DAC
   working point does the BASKET prototype run? (They quote 21 fC expected
   signal and 62 fC threshold-ish floor — clarify what "62 fC–2 pC" is:
   dynamic range at which gain?)
2. **Measured noise** (pedestal σ in DAC counts / equivalent fC) on real
   pads at 75–170 pF — replaces the `enc_electrons` placeholder. Published
   VMM data doesn't cover this capacitance.
3. **PDO calibration** (counts ↔ mV ↔ fC) and effective ADC range for
   saturation modeling (`adc_full_scale_mv` is a placeholder; ~8-bit
   effective resolution per the VMM papers).
4. **Which mapping revision does the DAQ use?** *(rewritten 2026-08-06 — the
   earlier "the two revisions disagree on 79/1280 pads" was a rounding
   artifact in the comparison script, now fixed. The pad plane is identical
   to 2.5 µm.)* The revisions disagree on the **readout order**: only
   11/1280 (connector, channel) pairs land on the same pad. That decides
   whether NL reads neighbors 12 mm away or 126 mm away (§3.1), and it is
   needed for any per-channel comparison with test-beam data, dead-channel
   masks included. Still open, still the same question to ask — but it is a
   *channel-assignment* question, not a geometry question.
   Sub-question, now closed: whether NL crosses the 64-channel chip boundary
   changes 0.8 % of pairs — **does not matter**.
5. **Will NL be enabled at all?** Working assumption (Dylan, 2026-08-06): no.
   Confirm with BASKET, and if the answer is "we could", the Phase-2 scan
   should quote what it buys (bounded at ~3–4 % of tracks gaining a partial
   second pad) against ~3× the channel occupancy.
6. **Timing configuration** *(new)*: TDO mode (threshold-crossing vs
   time-at-peak), TAC ramp (60/100/350/650 ns), BC clock, per-channel time
   calibration. Needed to compare against the SPS timing distributions —
   see `../docs/research/TIME_RESOLUTION_NOTES.md` §5.
7. **Streaming mode semantics**: which VMM readout mode will P2 stream
   (continuous mode presumably)? Affects dead-time modeling only at rate
   studies (Phase 4), not the per-event ADC cut.
8. **Pad-to-pad capacitive cross-talk**: ATLAS strip values (0.3/0.09)
   don't transfer to pads; measure or neglect with a stated bound. Note this
   is a *different* coupling from NL and does follow physical adjacency.
9. **Ion-tail suppression** (VMM3a mild/strong): changes the effective
   ballistic deficit; not modeled — relevant only if t_peak < 150 ns is
   considered.

## 8. Planned next steps (in order, all cheap)

1. ✅ *(done 2026-08-06)* **Pad adjacency helper** → `nl_map.py`, with the
   channel and geometric relations kept separate.
2. **Threshold-scan driver**: given a set of Stage-B event files, produce
   ε_e(threshold) and P_γ(threshold) curves + ROC per (gas, gap) — this is
   campaign plan §5 step 4; the emulator API is already shaped for it.
3. Add **TDO quantization + timestamp mode** (TAC ramp, BC clock,
   threshold-crossing vs time-at-peak) to T1 — promoted from "only if
   needed" now that timing is a deliverable (§5); `time_resolution.py`
   already models both, so this is porting, not research.
4. Validate T1 against T0 on Stage-B-like toy events (expected: near-equal
   at t_peak = 200 ns for our ≤150 ns drift spans — the T0 tier is then
   preferred for the big scans).
5. *(added 2026-08-05)* **Ballistic-deficit toy study** — δ-arrival
   (photon point deposit) vs uniform-arrival-over-T_drift (track) events
   through T1 across t_peak ∈ {25, 50, 100, 200} ns × an ENC grid:
   quantify the PDO separation factor and the ε_e cost. No Stage B or
   Geant4 needed; first concrete deliverable of
   `../docs/research/TIMING_PSD_NOTES.md` (§2, §8.1). *Partial input already
   available:* `time_resolution.py` measures the track-side efficiency cost
   of short peaking at fixed threshold (at 2 fC: 99 % → 78 % going from
   t_p = 100 → 25 ns in Ar/CO₂/Iso, and 97 % → 42 % in Ne/CH₄), which is the
   price side of that trade.
6. *(added 2026-08-06)* **σ_t re-run with Magboltz v_d/D_L** once P0.10
   lands, and σ_t added as a Phase-3 matrix cell value.

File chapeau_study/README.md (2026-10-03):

# Chapeau (Al) low-energy-photon study — analytic, no Geant4

Question: can ~119-144 MeV back-scattered electrons (P2 155 MeV beam, elastic
e-p at 140-150 deg -> 119 MeV; 200 MeV option -> 144 MeV; see
`../docs/P2_EXPERIMENT.md` s3) crossing an aluminium chapeau wall make the
low-energy photons seen in the sim?

Run: `python chapeau_photons.py` -> table on stdout + `chapeau_photons.png`.

## Assumptions (nothing about the chapeau is in this repo)
- Al wall, thickness **unknown** (scanned 0.5-5 mm), incidence 10 and 40 deg.
- Sources: primary Bethe-Heitler brems + brems of knock-on electrons. Compton/
  photoabsorption of the hard brems photons, Al fluorescence (1.5 keV, dies in
  microns), TR not modelled. Delta-ray part is good to ~factor 2.
- NIST XCOM attenuation (Al, Ar). Gas gap taken as 3 mm pure Ar, 1 atm.

## Result (per incident electron, photons that exit the wall)
| t (Al) | 5-30 keV | 30-150 keV |
|---|---|---|
| 1 mm | ~1e-2 | ~2.4e-2 |
| 2 mm | ~1.3e-2 | ~4.7e-2 |
| 5 mm | ~1.7e-2 | ~1.1e-1 |
- Scales ~ t/X0 (X0(Al)=8.9 cm); delta-ray brems is a <10% correction.
- Energy-independent between 119 and 144 MeV (brems ~ 1/k, E only sets the cutoff).
- Below ~10 keV the wall itself absorbs them (mu*rho*1 mm ~ 70 at 10 keV).
- Photons are collinear with the electron (MS cone ~1 deg for 2 mm), i.e. they
  arrive with the electron in the same pad/time, not as separate hits.
- Conversion in the 3 mm gas gap: ~1e-4 per electron -> negligible vs. a MIP.

## Caveat / follow-up
Plausible yes as a *photon-count* source (a few % of electrons carry a 30-150 keV
photon), but this is far below the ~1e3 photon/electron design background and the
yield is a smooth 1/k, so it would not make a peak. To compare we need the sim's
actual low-energy photon spectrum + production-process/volume tags, and the real
chapeau thickness. Real Geant4 run (e- at 119 MeV into Al slab + gas, tag by
creator process) is the follow-up.

## Wall thickness estimate (`wall_estimate.py`) and yield plots (`plot_yield.py`)
Freestanding flat Al plate, clamped, Al 6061-T6, SF 3, deflection limit 1-3 mm
(gap is only 3 mm). Span and overpressure are unknown: ~10 mbar over a
150-300 mm half-span gives 0.5-1 mm (stress) to 1-3 mm (stiffness). A real
1 bar-rated wide window would be 5-12+ mm. **Nominal 2 mm, band 1-5 mm.**
Plots: `yield_vs_energy.png` (1/2/5 mm), `yield_by_process.png` (2 mm,
primary vs delta-ray brems, produced vs exiting).

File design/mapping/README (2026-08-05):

Descriptif
----------

Fichiers : connector_i.txt, i=0..9

Dans chaque fichier :

Connector	index connecteur		0..9		sens trigo
		 
Channel		index canal / connecteur	0..127		sens trigo

PadIndex	index pad / connecteur		0..127		sens trigo pour connecteurs 0..4
		       	     					sens trigo inverse pour connecteurs 5..9

AbsIndex	index pad absolu		0..1279		sens trigo

Radius		rayon pad

Phi		azimuth pad

DeltaPhi	difference en phi avec le precedent

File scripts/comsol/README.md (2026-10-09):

# COMSOL mesh unit cell (P2)

Base model: `MeshUnitCellIon_PressureStudy.mph` (a colleague's woven-mesh unit
cell, COMSOL 6.3, used with permission). Not in the repo (850 MB); a copy is
on EOS: `/eos/user/a/akallits/p2_sim/comsol/`.

Runs on lxplus with COMSOL 6.4 from CVMFS
(`/cvmfs/projects.cern.ch/engtools/comsol/comsol64/multiphysics/bin/comsol`)
and the CERN licence server (`licencomsol.cern.ch:1718`; needs COMSOL +
AC/DC, both available as batch licences).

| file | what |
|---|---|
| `InspectMeshCell.java` | prints parameters, studies, physics, datasets, export nodes |
| `SolveP2MeshCell.java` | sets P2 parameters, solves Study 1, re-runs the Garfield exports |
| `run_mesh_cell.sh`, `mesh_cell.sub` | HTCondor wrapper (8 cores, 24 GB) |

    comsol compile SolveP2MeshCell.java
    condor_submit mesh_cell.sub

P2 settings (SPS July 2026; mesh and drift polarised, pads grounded):
pitch 2×68 µm (measured 18 µm wire / 50 µm opening; the weave repeats every
two wires), rWire 9 µm, meshHeight 150 µm, VAnode 0, VMesh −450 V, drift
field 625 V/cm: h4mm = height 4 mm, VCathode −700 V; h2mm = 2 mm, −575 V.

Output: `/eos/user/a/akallits/p2_sim/comsol/p2_sps/<case>/mesh.mphtxt` +
`potential.txt` (Garfield `ComponentComsol`). Materials: gas ε=1 (domains
1–3), mesh/insulator ε=4 (domains 4–11).

Gotchas
- COMSOL's default security settings forbid Java file I/O and reading
  system properties in a batch class: make folders in the wrapper, print to
  the log, hard-code paths.
- Never let COMSOL save the model to AFS (quota); run with `-nosave`,
  `-tmpdir`/`-recoverydir` on the job scratch.
- In the base model the weighting-potential exports (data2–4, V2/V4/V5) are
  disabled and Study 1 solves only `V`; enable them if the cell's own
  weighting fields are ever needed.

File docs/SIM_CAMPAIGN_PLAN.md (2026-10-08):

# P2 wedge simulation campaign — plan

**Written:** 2026-08-05. Status: **planning — execution gated on Alexandra's
geometry review** (see `P2_MODEL.md` §"Still to confirm"). Companion docs:
`SIM_CAMPAIGN_BRIEF.md` (capabilities snapshot), `P2_EXPERIMENT.md` (rates,
kinematics), `P2_MODEL.md` (as-built geometry),
`research/TOOLCHAIN_NOTES.md` (Geant4/Garfield++/Magboltz/VMM citations),
`research/GAS_NOTES.md` (neon mixtures, flammability, procurement
citations), `TESTBEAM_PLAN.md` (SPS 200 GeV muon test-beam comparison —
the data-anchoring track that feeds tuned parameters back into this
campaign), `research/TIMING_PSD_NOTES.md` (time-structure discrimination
blue-sky, 2026-08-05), **`research/PHOTON_DISCRIMINATION_NOTES.md`
(2026-08-05, late — the 50–100 keV cross-section reality check, the
energy-deposition discrimination handle, and the wall-conversion floor;
§0, §1, §3, §4.2, §5, §7 and §10 below are amended from it)**,
**`research/TIME_RESOLUTION_NOTES.md` (2026-08-06 — predicted per-pad σ_t
and the SPS comparison protocol; §2, §5 step 5, new §5 step 7 and §6 are
amended from it)**.

> **Amendment 2026-08-06 (Dylan).** Two operating facts now shape the Stage C
> plan: (1) the charge cloud fires **~1.1 pads on average**, so inter-pad
> clustering is a ~10 % effect and **VMM neighbor logic — a strip-detector
> feature whose channel neighbors are not spatial neighbors on this pad
> plane — is off in the baseline** (§2, `vmm/README.md` §3.1); (2) **VMM
> time resolution is a headline deliverable**, to be compared against the SPS
> data (§2, §5 step 7, `research/TIME_RESOLUTION_NOTES.md`).

---

## 0. Purpose and key questions

Single-wedge response study: how well can one P2 wedge **detect ~30–160 MeV
electrons while rejecting the 50–150 keV photon background** that arrives at
~10³× the electron rate? The experiment plans trigger-less VMM3a streaming
with online 3-wheel track matching; single-photon hits are rejected by (a) the
per-hit **ADC/charge cut** and (b) the **3-layer coincidence**. This campaign
quantifies (a) directly and provides the per-layer inputs for estimating (b).

**Premise revised 2026-08-05 (late).** The campaign was built around
"switch from argon- to neon-based gas": MX17 studies suggested Ne mixtures
are far less sensitive to keV–100 keV photons while costing only ~30 % of
the electron primary-ionization signal. Colleagues have since fixed the
expected background band at **50–100 keV with a higher-energy tail**, which
is far above the Ar K-edge, and the analytic pass in
`research/PHOTON_DISCRIMINATION_NOTES.md` finds that premise does not
survive there:

- The Ar/Ne interaction-probability ratio falls from 5.4× at 50 keV to
  2.5× at 100 keV and asymptotes to 1.8× (the electron-density ratio).
- **Conversions in the walls — steel mesh and copper pad plane — outnumber
  gas conversions by ~15× (Ar) to ~65× (Ne)**, and that floor is
  gas-independent. Total fake sources differ between Ar/Iso and Ne/Iso by
  under 10 %, against a 30× worse zero-cluster floor for neon.

So **argon and neon are now co-baselines**: the gas scan still runs (neon's
verified advantages are max-gain headroom and discharge probability, not
photon blindness), but photon rejection is no longer the argument for it,
and the conversion-layer budget — not the sensitivity curve — is the
decision variable.

**Second thread, added the same day: energy-deposition discrimination.**
Electrons are MIPs and leave a Landau spectrum; both Compton and
photoelectric conversions should leave more. The note quantifies it at
3–30× the MIP deposit in the band (not the 10–100× that ⁵⁵Fe intuition
suggests, because at 50–100 keV the photoelectron's range is 1–8 cm of gas
and it *crosses* the 3 mm gap rather than stopping in it). The handle is
real and sets the charge window, but its target population is the minority
one — wall photoelectrons crossing the gap are both dominant in rate and
MIP-like in charge *and* in time. See §5 step 3a and P0.12.

**Measured 2026-08-05** (§1.1, after the P0.1 gas fix): the wall-dominance
prediction held — walls are **90 % of fakes in argon, 97 % in neon**, and
argon → neon removes only **(12 ± 3) %** of photon-induced hits. But the
wall photoelectrons sit at a **median 567 eV against a measured MIP median
of 738 eV** — MIP-sized, not above. So the *upper* charge cut, which §0.3
and §5.4 were built around, barely touches the dominant fake class; the
**lower threshold** is the cut that acts on it, and it pays in ε_e
directly. The upper cut still works on the ~10 % of fakes that are
point-like gas conversions and fluorescence blobs. Both cuts must be
scanned independently and reported per class. Note also that **argon
separates slightly better than neon** (wall fakes at 0.77× the Ar MIP
median but 1.05× the Ne one).

The campaign must answer, per (gas, drift gap):

1. **Electron efficiency** — P(detectable signal above ADC threshold), as a
   function of energy, angle, position.
2. **Photon response** — P(fake hit above the same threshold) per incident
   photon vs energy, *and which layer the conversion happened in* (gas choice
   only helps against gas conversions; wall conversions set a floor).
3. **Discrimination power** — the ROC of electron efficiency vs photon
   acceptance as the charge **window** (lower + upper cut) scans, per
   configuration. A converted photon typically deposits *more* charge than
   a crossing electron — **3–30× the MIP deposit in the 50–100 keV band**
   (revised down from "10–100×", which applies to a fully contained few-keV
   photoabsorption such as ⁵⁵Fe, not to this band) — so the upper cut, the
   time structure (§5 step 6) and the coincidence carry the rejection; the
   lower threshold only removes partial-clip deposits and noise. Report the
   ROC **split by conversion class** (gas-photoelectric, gas-Compton,
   fluorescence re-absorption, wall photoelectron), because the classes have
   very different rejectability and very different rates.
4. **Operational numbers** — pad multiplicity (streaming bandwidth), drift
   time span (coincidence window), gain requirements.

## 1. Physics framing — what to expect before simulating

Primary-cluster statistics dominate thin-gap efficiency. Component values
from **PDG 2024 Table 35.5** (n_p = primary clusters/cm at MIP; compilations
vary — Phase 1 re-derives these with our own tools):

| component | n_p [/cm] | n_tot [/cm] | W [eV] | dE/dx min [keV/cm] |
|---|---|---|---|---|
| Ne | 13 | 40 | 37 | 1.45 |
| Ar | 25 | 97 | 26 | 2.53 |
| CH₄ | 28 | 54 | 30 | 1.61 |
| C₂H₆ | 48 | 112 | 26 | 2.91 |
| iC₄H₁₀ | 90 | 220 | 26 | 5.67 |
| CO₂ | 35 | 100 | 34 | 3.35 |
| CF₄ | 52–63 | 120 | 35–52 | 6.38 |

Volume-weighted n_p and the **zero-cluster (hard inefficiency floor)**
P₀ = exp(−n_p·d) at normal incidence (CF₄ taken at n_p = 52):

| mixture | n_p [/cm] | P₀ @ 1 mm | @ 2 mm | @ 3 mm | @ 4 mm |
|---|---|---|---|---|---|
| Ar/Iso 95/5 | 28.3 | 5.9 % | 0.35 % | 0.021 % | 0.001 % |
| Ar/CO₂/Iso 95/3/2 | 26.6 | 7.0 % | 0.49 % | 0.034 % | 0.002 % |
| Ar/CF₄/Iso 88/10/2 | 29.0 | 5.5 % | 0.30 % | 0.017 % | 0.001 % |
| Ne/Iso 95/5 | 16.9 | 18 % | 3.4 % | 0.64 % | 0.12 % |
| Ne/Iso 90/10 | 20.7 | 13 % | 1.6 % | 0.20 % | 0.025 % |
| Ne/Iso 80/20 | 28.4 | 5.8 % | 0.34 % | 0.020 % | 0.001 % |
| Ne/CF₄ 90/10 | 16.9 | 18 % | 3.4 % | 0.63 % | 0.12 % |
| Ne/CO₂/Iso 95/3/2 | 15.2 | 22 % | 4.8 % | 1.05 % | 0.23 % |
| Ne/Iso/CO₂ 90/5/5 | 18.0 | 17 % | 2.8 % | 0.46 % | 0.076 % |
| Ne/CH₄ 93/7 | 14.1 | 24 % | 6.0 % | 1.5 % | 0.36 % |
| Ne/C₂H₆ 90/10 | 16.5 | 19 % | 3.7 % | 0.71 % | 0.14 % |

Take-aways that shape the campaign:

- **Gap and gas interact strongly.** Ne/Iso 95/5 at 3 mm has the same
  cluster-count floor as Ar/Iso at ~1.7 mm. Small gaps + neon is the risky
  corner; that is where cluster-statistics fidelity (PAI/Heed, not just
  edep/W) matters most.
- **Quencher fraction is a powerful knob**: Ne/Iso 80/20 recovers Ar-level
  primary statistics — but is deeply flammable. The flammability boundary
  (ISO 10156:2017: ~2.4 % isobutane in binary Ne for any-air-ratio
  non-flammability; details §7) is therefore a first-class constraint, not
  a detail.
- The real efficiency is worse than P₀ once the ADC threshold is applied
  (few-cluster events × gain fluctuations fall below cut) — exactly what
  Phase 2 computes.
- At 50–150 keV, photon interactions in the **solids** (Cu pads, steel mesh,
  Al on cathode) do not merely compete with gas photoabsorption — the
  analytic pass says they **dominate it by 15–65×**, now confirmed in
  simulation (details and the
  per-layer table in `research/PHOTON_DISCRIMINATION_NOTES.md` §4). So the
  per-layer conversion breakdown (Phase 1) decides how much a low-Z gas
  actually buys, and on present numbers the answer is "very little". The
  per-hit charge spectra (Phase 2) decide what the ADC cut can do; the
  3-layer coincidence handles what survives, and we feed it accidental-rate
  inputs.

### 1.1 Photon side — the analytic targets (added 2026-08-05)

Numbers the first photon runs must reproduce, from
`scripts/photon_budget.py` (NIST μ/ρ, Klein-Nishina, Katz-Penfold ranges).
Per incident photon, 3 mm gap, pure gas at 1 atm:

| E [keV] | P_int(Ar) | P_int(Ne) | ratio | Compton ⟨T⟩ | photoelectron range in Ar |
|---|---|---|---|---|---|
| 50 | 3.49×10⁻⁴ | 6.49×10⁻⁵ | 5.38 | 4.0 keV | 12 mm |
| 60 | 2.32×10⁻⁴ | 5.44×10⁻⁵ | 4.27 | 5.6 keV | 17 mm |
| 80 | 1.38×10⁻⁴ | 4.48×10⁻⁵ | 3.07 | 9.4 keV | 28 mm |
| 100 | 1.02×10⁻⁴ | 4.03×10⁻⁵ | 2.53 | 13.8 keV | 41 mm |
| 150 | 7.11×10⁻⁵ | 3.45×10⁻⁵ | 2.06 | 27.2 keV | 80 mm |

Wall injection per incident 60 keV photon: mesh 2.0×10⁻³, pad Cu 2.0×10⁻³,
mylar layers 5×10⁻⁵ — versus 2.3×10⁻⁴ (Ar gas) and 5.4×10⁻⁵ (Ne gas).
Plus a **fluorescence chain** (Cu-K 8.05 keV from the pad plane, Fe-K
6.4 keV and Cr-K 5.4 keV from the stainless mesh, re-absorbed in the gas as
a point-like ~8–10× MIP blob) at ~1.8×10⁻⁴ in Ar but ~1.7×10⁻⁵ in Ne — the
one genuinely gas-sensitive wall channel, and the one the charge window
kills best.

**✅ Confirmed by simulation, 2026-08-05** (4×10⁵ γ at 60 keV in each of
Ar/Iso and Ne/Iso, 3 mm, **after** the P0.1 gas fix;
`research/PHOTON_DISCRIMINATION_NOTES.md` §4.3a, `research/GAS_FIX_NOTES.md`).
Measured photon-induced hit rate **3.53×10⁻³ (Ar) vs 3.11×10⁻³ (Ne)** — a
**(12 ± 3) % reduction**, against 77 % if only the gas mattered.
Conversion-layer budget **Micromesh 2.10×10⁻³, PCB_Cu_F 1.03×10⁻³, DriftGas
3.10×10⁻⁴** (Ar): walls are **90 % of fakes in argon, 97 % in neon**, and
the mesh rate agrees between the two gases to 1.4 % — the internal check
that the floor is gas-independent. All fluorescence lines appear at the
right energies (Cu-K 7.98/8.01, Fe-K 6.36, Cr-K 5.38 keV).

**Two predictions were wrong and both matter.** (i) Wall photoelectrons
deposit a *median 567 eV* in argon against a measured MIP median of 738 eV
— they are **MIP-sized or smaller**, not the 3–5× MIP §0 assumed. So the
**upper** charge cut barely touches the dominant fake class; only the lower
threshold does, at direct cost to ε_e. (ii) **Argon separates marginally
better than neon**: wall fakes sit at 0.77× the Ar MIP median but 1.05× the
Ne MIP median, i.e. in neon the dominant background is indistinguishable
from signal by charge alone. The cleanly separable classes (gas
photoelectric ~8× MIP, fluorescence ~9×, gas Compton ~6×, all point-like)
are only ~10 % of argon fakes and ~3 % of neon's.

Consequences for reading Phase-1 results: Compton electrons below ~80 keV
photon energy are **contained** in 3 mm (practical range 0.14 mm at 60 keV
in Ar) and deposit their full energy; photoelectrons in this band are
**not** contained and deposit only 3–11 keV of their 50–100 keV. Rayleigh
scattering deposits nothing and must not be counted as an interaction.
⬜ **NEEDED: the actual incident photon spectrum** — soft (≈50 keV) vs hard
(≥100 keV) moves the Ar/Ne ratio between 5× and 2×.

## 2. Simulation chain — architecture

Three factorized stages, joined by files (each stage re-runnable alone):

```
Stage A  Geant4 (this repo)         geometry, transport, conversions
         → ClusterTree: ionization clusters (x,y,z, edep, nPrim, provenance)
Stage B  Response (new, Python + Garfield++/Magboltz gas tables)
         drift + diffusion + mesh transparency + Polya gain + pad summing
         → pad hits: (pad, charge [fC], time)
Stage C  Electronics + analysis (new, Python)
         threshold/ADC model (VMM-informed), efficiency/ROC/multiplicity
```

**Geant4 ↔ Garfield++ coupling decision** *(research pass done 2026-08-05;
citations below)*. Garfield++ does hook into Geant4: the official interface
(Pfeiffer, De Keukeleere, Schindler, Veenhof et al., *Interfacing Geant4,
Garfield++ and Degrad for the simulation of gaseous detectors*, NIM A 935
(2019) 121, arXiv:1806.05880; `Examples/Geant4GarfieldInterface`) attaches a
Garfield "fast-simulation model" to a G4Region over the gas, killing Geant4
tracks there and handing them to Heed/Magboltz classes. It is the right tool
for single-configuration validation runs, but it makes one monolithic binary
whose slowest stage (avalanching) throttles everything and re-does Geant4
transport at every parameter point. For a campaign, the **staged pipeline is
the established pattern** — it is literally how ATLAS NSW Micromegas
digitization and the CAST/IAXO Micromegas background chains work (Geant4
deposits → Garfield/Magboltz-*parameterized* drift, diffusion, Polya gain,
electronics):

- **Geant4 standalone (Stage A)** handles all materials, photon conversions,
  deltas — everything needing the full geometry. Use Livermore/Penelope-class
  EM with atomic deexcitation ON (`/process/em/fluo`, `auger`, `pixe`) so
  Cu-K 8.0 keV / Fe-K 6.4 keV fluorescence and Auger cascades are produced.
- **In-gas ionization statistics**: Geant4's default condensed-history EM is
  *not* adequate for cluster statistics in 1–4 mm of gas (right mean, wrong
  event-by-event distribution — the thin-absorber problem). Two remedies,
  used in tiers: (i) **PAI model** in a G4Region over the gas volumes —
  benchmarked against Heed in the Pfeiffer paper, cheap (~2× EM cost);
  (ii) for the threshold/efficiency studies, **re-ionize gas crossings with
  Heed** (`TrackHeed::NewTrack()`) in Stage B from exported track segments
  (entry point, direction, momentum, PID) — Heed is the MPGD standard for
  cluster counts and cluster-size distributions, and it is what the Pfeiffer
  paper recommends for relativistic particles in gas. So Stage A exports
  *both* clusters (edep/W, PAI-informed) and gas-crossing track segments;
  Stage B chooses fidelity per study.
- **Magboltz gas tables, once per gas** (`MediumMagboltz::GenerateGasTable`
  → `WriteGasFile`): drift velocity, D_L/D_T, Townsend, attachment on a
  log E-grid spanning drift and amplification fields. Accuracy: ncoll≈10 is
  high precision; cost ~minutes per E-point for quenched mixtures at 1 atm
  (order an hour per 20-point table per core — benchmark, no official
  numbers published). Cache `.gas` files; never regenerate per job.
  **Penning transfer must be enabled** — without it simulated MM/GEM gains
  are low by large factors. Published r values (Şahin/Kowalski/Veenhof
  series, JINST 5 (2010) P05002; JINST 16 (2021) P03026; Garfield++
  built-ins): Ar/iC₄H₁₀ (10 %) r = 0.40, Ar/CO₂ 93:7 r = 0.405,
  **Ne/CO₂ 90:10 r = 0.577**, Ar/CF₄ r ≈ 0 (CF₄ IP above Ar* levels).
  **Gaps: no published r for Ne/iC₄H₁₀, Ne/CF₄, or any ternary** — the
  argument-free `EnablePenningTransfer()` works for binaries only. For our
  Ne mixes: apply the binary noble-gas r manually, bracket ±, and treat
  absolute gain as calibration-anchored (below).
- **Stage B is a lightweight sampler**, not per-electron microscopic
  avalanches: drift each electron with Gaussian diffusion σ_{L,T}·√z from
  the tables, mesh transparency ε_mesh(E_drift/E_amp) (flat ≈100 % for field
  ratios ≲0.01, steep drop above), Polya-fluctuated gain (θ ≈ 1.5–2.5 for
  Ar-mix Micromegas, Zerguerras et al., NIM A 772 (2015) 76), pad summing.
  **Electrons born inside the amp gap** (pad-Cu/mesh photoelectrons, direct
  amp-gas conversions) must get z-dependent partial gain from their birth
  depth — birth at the pad surface ⇒ ~no gain, mesh side ⇒ full gain; this
  population is a plausibly dominant wall-fake channel and a flat full-gain
  treatment misestimates it.
  Cost: µs per electron → full campaign trivial.
  **AvalancheMicroscopic is used once per (gas, HV) point** on ~10³–10⁴
  single electrons to *extract* ḡ, θ, transparency (cost scales linearly
  with avalanche size — seconds per avalanche at gain 10⁴, not viable as
  workhorse; cf. Garfield++ CUDA paper arXiv:2509.15377), then frozen into
  the sampler.
- **Absolute gain calibration**: integrated Penning-corrected Townsend,
  anchored to measured curves (BASKET prototype, published bulk-MM data).
  Report results vs *gain* and vs threshold in primary-electron equivalents
  so the gain-scale uncertainty stays factorized.
- **Degrad** (full shell-resolved photoabsorption + Auger + shake-off in
  gas; Fano-exact to <3 % below 20 keV) is needed only if the exact
  electron-count distribution of few-keV gas photoabsorption becomes
  decision-relevant (escape-peak topology, Fano-limited resolution). Held as
  a Phase-4 one-time validation of the 3–10 keV response; Geant4 deexcitation
  + Heed `TransportPhoton()`/W+Fano covers the campaign need.

**VMM3a modeling (Stage C)** *(chip: 64 ch, 3rd-order DDF shaper, peaking
25/50/100/200 ns, gains 0.5–16 mV/fC, 10-bit peak ADC (~8-bit effective),
neighbor logic; Iakovidis et al., NIM A 955 (2020) 163306)*. Two published
response models exist: the **ATLAS Athena `VMM_Shaper` closed-form h(t)**
(pole/residue form, ~20 lines of code, includes peak detection, ballistic-
deficit scale factor vs the ~150 ns ion tail, neighbor-logic emulation), and
the ESS/CERN CR-RC³ semi-Gaussian proxy (Backis, Piscitelli, Pfeiffer et
al., arXiv:2510.01981). **Charge-integration per pad + threshold is a
defensible baseline** (at t_p = 200 ns essentially the whole MM signal is
integrated, so peak ≈ ∝ collected charge) with three required corrections:
(i) threshold set in ENC units on the shaped amplitude — noise at the P2 pad
capacitance **75–170 pF** sets the floor (several-thousand-e⁻ ENC → few-fC
practical thresholds; BASKET expects ~21 fC signals, range 62 fC–2 pC);
(ii) ballistic-deficit factor if t_p < 150 ns is ever modeled;
(iii) ~~neighbor logic~~ — **re-scoped 2026-08-06, see below**.
Also simulate explicitly: **ADC saturation** — at high gas gain a 6–8 keV
photoabsorption (~250 e⁻ point deposit) can saturate the ~8-bit range while
MIP pads stay in range; saturation interacts with the discrimination cut.
Full waveform simulation with the Athena h(t) is Phase 4, needed only for
time-walk modeling beyond the (PDO, TDO) pair or streaming pile-up studies.
**Implementation started (2026-08-05): `vmm/`** — Athena shaper ported to
Python and unit-tested, channel emulator with T0 (charge+threshold) and T1
(shaper + neighbor logic + ENC + ADC) tiers, Stage-B interface contract and
NEEDS-DATA list; see `vmm/README.md`.

**Neighbor logic is a strip feature and mostly does not apply here**
*(2026-08-06, from Dylan's operating input + `vmm/nl_map.py`)*. Two facts:

- **The charge cloud fires ~1.1 pads on average.** Inter-pad clustering is a
  ~10 % minority effect — real, and to be used optimally, but not a design
  driver. It is *not* the multi-strip cluster that NL, µTPC and cluster-size
  cuts were designed for; anything inherited from ATLAS NSW that assumes a
  several-channel cluster has to be re-derived, not transplanted.
- **NL fires on chip-channel neighbors, and on a pad plane those are not
  spatial neighbors.** Measured over all 1280 pads: in the 9-column mapping
  revision chan ±1 is a touching pad 73.8 % of the time (median separation
  11.9 mm) and covers 25 % of the 5.78-pad physical neighborhood; in the
  7-column revision it is **7.7 %** and **126 mm median** — NL there would
  triple the data volume reading pads across the wedge. P(the actual
  charge-sharing partner is in the NL set) = **36 % / 2 %** respectively.

Consequences adopted for the campaign: **baseline is NL off** (the experiment
does not plan to use it, and the upside is bounded at ~10 % of tracks × 36 %
coverage ≈ 3–4 % of tracks gaining a partial second pad, against ~3× channel
occupancy); **clustering is an offline geometric step** on pads that each
passed threshold, which works with NL off and is where the real inter-pad
sharing gets used; and if NL is ever enabled it must be simulated in
*channel* space with the revision stated. Modeling NL as "geometric
neighbors" — the placeholder in the original plan — simulates a detector we
do not have and would bias recorded cluster size in both directions.

**Timing is now a Stage C deliverable, not a Phase-4 option** *(2026-08-06 —
"we are very interested in the time resolution of VMM and would definitely
want to compare what we get at SPS with simulation")*. First quantitative
pass done: `vmm/time_resolution.py` +
`research/TIME_RESOLUTION_NOTES.md`. Predicted per-pad σ_t (3 mm, gain 10⁴,
2 fC, ENC 3 k e⁻, threshold-crossing timestamp, walk-corrected with the same
hit's PDO): **10.6 ns Ar/Iso, 12.1 ns Ar/CO₂/Iso, 15.0 ns Ne/Iso 90/10,
16.2 ns Ne/CH₄, 25.0 ns Ne/CO₂/Iso 95/3/2** at t_p = 100 ns. The result is
**σ_t ≈ (1.0–1.5)/(n_p·v_d)** — ionization statistics, not electronics:
ENC jitter, TAC quantization, Polya and diffusion together contribute < 3 ns
in quadrature. The cost is one toy run per configuration (~1 min), so σ_t
can be carried through the Phase-3 matrix as a cell value rather than
computed once. Note **µTPC is unavailable at 1.1 pads/hit** — one timestamp
per hit, so gas/threshold/peaking time are the only knobs.

## 3. Phase 0 — preparation (code + infrastructure)

Do now (none of it depends on Alexandra's answers):

| # | task | notes |
|---|---|---|
| P0.1 | **Fix gas mixture composition bug** ✅ **done 2026-08-05** (see `research/GAS_FIX_NOTES.md`) | `makeMix2/3` feeds volume fractions to `AddMaterial()` which takes **mass** fractions. Negligible-ish for Ar/Iso (5 % vol = 7.3 % mass) but fatal for Ne mixes (Ne/Iso 95/5 vol = 86.5/13.5 by mass). Rewrite builder to take vol% + component molar masses → mass fractions; recompute densities from ideal-gas mixing. Also verify the 2.67e-3 g/cm³ isobutane density (ideal-gas at 20 °C gives 2.42e-3). |
| P0.2 | **Add campaign gases + W values** ✅ **done 2026-08-07** | All seven §7.4 mixtures are built and run: `ArCO2Iso9352`, `NeIso9010`, `NeIso8020`, `NeCO2Iso9532`, `NeIsoCO29055`, `NeCH4937`, `NeC2H69010` (+ `ArIso`). Composition, density, mass fractions and W now come from **one table** (`include/GasMixtures.hh`) instead of a composition list in `DetectorConstruction` and an unrelated hand-maintained W map in `SteppingAction` — the two used to be keyed by the same string with nothing checking they agreed, i.e. the same class of error as the 2026-08-05 mass/volume-fraction bug. `mm_sim --list-gases` prints the table; an unknown gas now fails at argument parsing with the list rather than core-dumping after geometry construction. **Three deviations from this task as written:** (i) mixture W is **stopping-power weighted**, not the harmonic *volume* weighting specified here — the correct weight is the energy fraction each species absorbs, which scales with molecular electron count, and the two differ by ~7 % for Ne/iC₄H₁₀ 90/10; (ii) CF₄'s W is a CLI parameter (`--w-cf4`) so the 35–52 eV spread is bracketed as run points rather than hardcoded, as asked; (iii) **Ne/CO₂/N₂ 90/10/5 was not added — those fractions sum to 105 %.** Someone needs to say what the intended mixture is before it can be built. |
| P0.2c | ⬜ **Re-source the pure-gas W values against PDG** *(new 2026-08-07)* | The component W table in `src/GasMixtures.cc` is inherited from the old `SteppingAction` map and has **not** been checked against a primary source. Isobutane is carried at 26.0 eV where the commonly quoted value is nearer 23.4 eV — a 10 % shift that would propagate into every `nPrimary` in every argon run. Deliberately left unchanged rather than silently moved, so previously produced numbers stay explicable. Cheap; do it before Phase 2 and record a source per component. Note the ordering: this matters *less* than Penning transfer, which is not modelled at all and makes every Ne-mixture W an upper bound. |
| P0.3 | **Gun angle control** ✅ **done 2026-08-07** | `--gun-theta` (deg from the wedge normal), `--gun-phi` (tilt azimuth), `--gun-standoff`. The beam **pivots about the aim point at the drift mid-plane**, so an angle scan re-illuminates the same pads instead of walking across the wedge with θ; the standoff auto-raises to clear the front window bulge at large θ. Verified against a 30° run: primary-track slope dx/dz = 0.5779 vs tan 30° = 0.5774, aim point stable to 16 µm. Unblocks the §4.1/§4.2 angle scans. `--beam-spread` also landed (2026-08-07). **The aim point has to be chosen against BOTH polar coordinates.** The historical default (r = 355 mm) sat 35 µm from a radial pad boundary; moving it to a ring centre then put it at φ = 30.0000°, which is 61 µm from the centre of a 126 µm *azimuthal* inter-pad gap. Measured with the real pad artwork: only **25.7 %** of events deposited in pad copper at all, against **100 %** at a true pad centre (⟨edepPadCu⟩ 4740 eV vs 20383 eV). The default is now a pad centre in both coordinates (305.385, 169.399), and `mm_sim` checks it against the gerber-derived table in `include/P2PadMap.hh` rather than a radial heuristic — it now catches the radial gap, the azimuthal gap, and off-pad-field aim points separately. |
| P0.4 | **Cluster provenance in output** ✅ **done 2026-08-05** | per cluster: creator process + logical volume where the depositing track (or its ionizing ancestor) was born. This is what turns photon runs into a per-layer conversion budget. Add per-event "first interaction volume" for γ runs. **Needs a `TrackingAction` + `G4VUserTrackInformation`, neither of which exists in the repo yet** (`ActionInitialization` registers only primary/run/event/stepping) — one-level `parentID` is not enough, since a δ-ray of a photoelectron reads as `eIoni`. Carry {origin process, origin volume, origin energy, ancestor trackID} and copy it to every secondary at creation. |
| P0.4b | **Gas-crossing track-segment export** | per charged track crossing DriftGas: entry point, direction, momentum, PID (a small `SegmentTree`). This is the Heed handoff for Stage B's high-fidelity mode (re-ionize with `TrackHeed::NewTrack()`), per the Pfeiffer-paper recommended split. Cheap to add now, enables the threshold studies later. |
| P0.4c | **Exit-particle export** | per event: every particle leaving the wedge envelope (PID, energy, direction, exit surface, creator process + birth volume, ancestry link to the primary). In photon runs this bounds **correlated multi-wheel fakes** (a Compton-scattered 100–150 keV photon keeps most of its energy and can convert again in wheels 2/3 — accidental-rate arithmetic misses this entirely) by pure wheel-to-wheel convolution, no 3-wheel geometry needed yet; it is also the input the eventual full 3-wheel sim (§8) will want. Decision 2026-08-05: save full interaction histories — track everything that produces signal, where it came from, and how it interacted. |
| P0.5 | **`--skip-empty` output flag** ✅ **done 2026-08-05** | photon runs are ≥99.9 % empty events; write only events with ≥1 cluster (keep the total-thrown count in metadata for normalization). |
| P0.6 | **PAI model in gas regions + deexcitation** 🟡 **deexcitation + fine-cut region done 2026-08-05; PAI still open** | G4Region over DriftGas+AmpGas with PAI/PAIphot (~2× EM cost, thin-layer straggling fixed); switch physics list to Livermore-class EM with fluorescence/Auger/PIXE on (needed for Cu-K/Fe-K fluorescence in photon runs). CLI switch to compare with default EM (one validation study early in Phase 1). **⚠ Includes a bug fix, do not skip:** `PhysicsList::SetCuts()` sets a **0.1 mm γ production cut**, which in copper is ~5–10 keV — i.e. the **8.05 keV Cu-K fluorescence line is at or below threshold and is probably being suppressed today.** That is the dominant *gas-sensitive* wall channel (§1.1). Set `G4EmParameters::SetDeexcitationIgnoreCut(true)` and add a fine-cut (~1 µm) `G4Region` over mesh + pad Cu + gas; the current 10 µm e⁻ cut is ~1 keV in gas but ~80 keV in Cu. |
| P0.7 | **Condor scripts refresh** | `submit_condor*.py` still speak MX17 modes; teach them the p2 flags + campaign manifest (one JSON/CSV row per run point). Also `collect_results.py`, which still parses MX17-style `{gas}_{particle}_{E}MeV` filenames and will not recognise the §9 naming scheme. **Half of this got easier on 2026-08-07** — see P0.21: the manifest fields the submit script would have had to record are now written into the ROOT file itself, so the script's job is to schedule and name runs, not to be the sole custodian of what a file is. |
| P0.21 | **Run provenance inside the output file** ✅ **done 2026-08-07** | New `RunMeta` tree, one row per worker (`hadd` concatenates; `thrown` sums). Carries the **thrown count** — the normalization denominator that previously existed *only* in stdout, making any file separated from its job log unnormalizable and, strictly, unidentifiable — plus the code git hash and a **dirty flag**, a hash + readable digest over every geometry-affecting parameter, the resolved gas composition/density/W, and the full beam configuration. `collect_results.py: read_run_meta()` sums thrown across workers and **warns** when rows disagree on git or geometry hash (an accidental merge across two run points) or when a run came from a dirty tree. This is what makes §9's "no un-manifested runs" enforceable rather than aspirational. Schema documented in `OUTPUT_FORMAT.md` §0. |
| P0.8 | **First lxplus build + geometry validation** ✅ **done 2026-08-05** | compile, overlap check, 100-event smoke run, one event display. Can be done with provisional geometry — worth doing *before* Alexandra's answers so her changes land in verified code. |
| P0.9 | **Stage B skeleton** ✅ **skeleton done 2026-08-07** | `stage_b/` runs end to end on real Stage A output: drift depth from the recorded frame → attachment → drift time → longitudinal and transverse diffusion → mesh transparency → Polya gain → polar pad lookup → per-pad charge and earliest arrival, written as a `PadHitTree` plus a `StageBMeta` tree carrying every assumption the run was made under. 16 closed-form self-tests (`python3 -m stage_b.selftest`) run without Geant4, so a Magboltz table is a genuine drop-in: `TransportTable` is the only interface to implement. **First result: 1.070 pads/event** (373 single / 26 double / 1 triple, 400 muons, Ar/iso, 3 mm) — which *independently reproduces* the ~1.1 pads/hit figure previously derived from the geometric analysis in `vmm/nl_map.py`. Two independent routes to the number the NL-off baseline rests on. Median pad charge 37.6 fC, drift span 0–60 ns as the placeholder predicts. **Four placeholders remain and are recorded in every output file**: gas transport (P0.10), induced current (P0.17), pillars (P0.16), constant mesh transparency (P0.13) — see `stage_b/README.md` §3 before quoting anything. *(On lifting MX17's digitizer: their package is real and good, but it is built around a 30 mm gap, 512×512 square pads, a resistive stack and DREAM. Our pad plane is polar, our gap is 3 mm and our charge cloud is ~1 % of a pad, so the parts that would have been lifted verbatim — the induction kernel and the electronics — are exactly the two plug-ins that differ. What was taken instead is their **hard-won knowledge**: the drift-frame trap, nPrimary-not-edep/W, the packet-vs-electron tradeoff, and recording assumptions in the product. Their §2.2 offer stands for the induction kernel when P0.17 happens.)* |
| P0.10 | **Magboltz gas tables** 🟡 **dry tables done 2026-10-08** for the six October-2026 gases (ArIso, ArIso9010, NeIso, NeIso8515, ArCO2Iso9352, ArCF4Iso; 40 E points 100 V/cm–90 kV/cm, ncoll 10), loaded in Stage B as `MagboltzTable` (default, `--drift-field`). **Still open: wet variants and Penning rates (needed for the gain).** | generate on lxplus per gas (log E-grid spanning drift ~100 V/cm–1 kV/cm and amplification ~30–60 kV/cm; ncoll = 10), `WriteGasFile` + ion mobility files, cache in repo or EOS. Order an hour per gas per core; embarrassingly parallel. Garfield++ comes from cvmfs LCG views on lxplus. Enable Penning transfer per §2 (manual r for Ne/iC₄H₁₀ and ternaries — document the chosen value and bracket). **Generate wet variants (0.5/1/2 % H₂O) alongside dry** *(MX17, 2026-08-06 — §2.4)*: MX17's bench finds water contamination dominates drift velocity — 36.6 µm/ns measured against a far higher dry prediction in Ar/iso, 1–2 % H₂O inferred at the SPS. Cheap (same job, one extra component) and it matters directly: σ_t ∝ 1/v_d, so a dry-only table can be optimistic by tens of percent against the SPS data we are trying to match. Quote a dry→2 % bracket rather than a line. |
| P0.11 | **Source mode** | isotropic point/disc source gun with line energies — ⁵⁵Fe 5.9/6.5 keV, ²⁴¹Am 59.5 keV, ¹⁰⁹Cd 88 keV, ⁵⁷Co 122/136 keV — plus the ⁹⁰Sr/⁹⁰Y β spectrum (CSV already in `sr90_calibration/`); configurable standoff. Powers the §5a source-validation predictions and the ⁵⁵Fe-vs-⁹⁰Sr timing bench test (`research/TIMING_PSD_NOTES.md`). |
| P0.12 | **Per-event interaction classification + edep by region** ✅ **done 2026-08-05** | the branch that makes the requested money plot a one-liner. Per event: `interactionClass` ∈ {none, gas-photoelectric, gas-Compton, gas-Rayleigh, wall-photoelectric, wall-Compton, fluorescence-reabsorption, MIP-crossing, other}, `conversionVolume`, `conversionZ`, plus **edep in every region, not just DriftGas/AmpGas** — `FrontGas`, `DriftCathode_Gas` and `BackGas` are currently unscored, so "converted somewhere that produces no signal" is indistinguishable from "did not convert". Also record amp-gap cluster z *relative to the mesh* explicitly (Stage B needs it for partial gain, §2). Then "event-by-event edep separated by interaction type" is one `TTree::Draw` per gas. Builds on P0.4's TrackingAction; do them together. |
| P0.13 | **Cylindrical-wire mesh cross-check** *(downgraded 2026-08-05 — see note)* | the mesh **is** the largest single fake source (measured 1.98×10⁻³ per 60 keV photon, 9× the argon gas rate), but the existing effective-density slab is **not** wrong about the rate: its areal density π·d²/(2·pitch) = 8.46 µm solid-equivalent is *exactly* the plain-weave value (verified). Only the escape geometry is approximate, and the diluted-slab and solid-wire estimates differ by ~1.4×, not 3×. So this is a **cross-check worth doing, not a blocker**. |
| P0.14 | **Analytic cross-check gate** ✅ **done 2026-08-05** | `scripts/photon_budget.py` reproduces the §1.1 targets; the first Geant4 photon run matched it (3.4×10⁻³ measured vs 4.3×10⁻³ predicted total, mesh dead on). Re-run this comparison after the P0.1 gas-mixture fix, since a mass/volume-fraction error shows up here first. |
| P0.15 | **Phase-space gun** *(new 2026-08-05, from `NEEDED_INPUTS.md` §1)* | read primaries (position, direction, energy, PID, weight) from a file at the wheel plane instead of the fixed pencil beam, so results can be weighted by the real spatial/angular distribution of signal electrons and background photons. Cheap to write; **blocked on the collaboration supplying the file**, which is the single highest-value external ask we have. |
| P0.17 | ⬜ **Realistic induced current — static Ramo, not a Phase-4 project** *(promoted out of §8 on 2026-08-07; MX17 §2.1)* | Stage B currently feeds the VMM shaper **delta charges** (Athena's model). The real Micromegas signal is a fast electron spike plus a ~150 ns ion tail, and that shape sets the leading-edge slope — the main model risk in the σ_t prediction and the only reason the time-at-peak estimator is untrustworthy. **P2's stack is non-resistive, so the weighting potential is static**: no time dependence, no FEM, no solver. Riegler's closed-form layered solutions (JINST 11 (2016) P11002) are already in Garfield++ `ComponentParallelPlate` (`AddPixel`/`AddStrip`). Replace each electron's delta charge with `i(t) = Q_e·δ_fast(t) + Q_ion·i_ion(t; µ_ion, gap)` weighted by the pad's Ramo potential. **Effort: an afternoon.** Also retires `MM_ION_FLOW_TIME_NS = 150.0` in `vmm/vmm_shaper.py` — an ATLAS NSW gap/gas constant that should be *dropped* once real induction exists, not retuned. Details: `research/TIME_RESOLUTION_NOTES.md` §4.1. **⚠ Read `HANDOFF_MX17_RESPONSE.md` §2.6 before implementing.** MX17 measured that grounding the inter-pad gaps in the weighting solve — which is exactly what `ComponentParallelPlate::AddPixel` assumes, since it treats the pixel as a patch of a continuous conductor — costs **+27.2 % on prompt captured charge** and invents a 4.5× sub-pad amplitude swing. It is a DC error that does *not* decay with distance from the plane. **Checked for P2, 2026-08-08: our gap fraction is 2.13 %** (metal fraction 0.9787, computed over all 42 rings from the gerber pad table in `include/P2PadMap.hh`; independently 0.9781 from that file's own header). Against MX17's 24 %, both of §2.6's scalings predict a **1.8–2.4 %** error for us — §2.6's own "≲2 %, fine at the percent level" branch. The polar geometry is what saves us: ~11 mm pads with ~126 µm gaps. So this route stands, with the ~2 % under-estimate of absolute captured charge quoted as a known-sign systematic. Note the affected quantities are *not* the ones P0.17 exists for: §2.6 reports ratios between pads and arrival times as barely affected (peak kernel +0.2 %), and σ_t and the time-at-peak estimator are what we are fixing. Revisit with MX17's `response/solver/v6_pad_gaps.py` only if absolute normalization or a sub-pad efficiency map becomes a deliverable. |
| P0.18 | ⬜ **Zone the readout copper — P2 has this error today** *(new 2026-08-07; MX17 §2.4 / `NEEDED_INPUTS.md`)* | `SimConfig.hh` documents `p2_fcu_coverage`/`p2_bcu_coverage` as measured **over the active area**, but `EffCu` applies them to a copper slab spanning the **whole wedge board** — so the model puts near-solid copper out in the fan-out and periphery, where real coverage is far lower. MX17 had the mirror-image bug (one board-wide average everywhere: 26 % too little copper in the active area, ~10× too much outside) and fixed it with two volumes and no measurable CPU — see `BuildReadoutZone` in `MX17_Geant/shared/MX17ModuleGeometry.hh`. **Why this is not cosmetic:** copper is ~90 % of the photon fake budget in argon (§1.1, and the first Geant4 photon run agreed), so mis-placing it distorts the conversion-layer budget that the entire gas decision rests on. **MEASURED 2026-08-07** (gerbers, exact vector geometry): inner margin r 95–115 mm F.Cu **0.123**; pad field r 115–594.9 mm F.Cu **0.913**, B.Cu 0.171; fan-out r 594.9–650 mm F.Cu **0.180**, B.Cu 0.235; whole board F.Cu **0.787** (was 0.937) and B.Cu **0.180** (was 0.181). So the old board-wide F.Cu sheet carried **25 % more copper than the artwork has**, most of it dumped in the inner margin and fan-out where there is almost none — while B.Cu's 0.174 was never materially wrong, only `P2_GEOMETRY.md`'s prose. Zoning is now implemented as 10 radial bands. **The coverage script had to be fixed first**: `analyze_cu_coverage.py` mis-measures F_Cu because `ApertureDef.size` returns `max(params)`, which for KiCad `RotRect` macro apertures picks up the *rotation angle* (e.g. `RotRect,0.3X1.8X302.763` → "size" 302.763 mm), painting ~151 mm-radius discs at the ten connector footprints; it also counts `NonConductor`/`Profile` apertures as copper. So `p2_fcu_coverage = 0.983` is itself inflated and must not be used as-is (`NEEDED_INPUTS.md`, verified 2026-08-07). |
| P0.19 | ⚠ **Real pad/strip artwork instead of a homogenized slab — CONTESTED, decide before building** *(new 2026-08-07; MX17 §2.4 item 2)* | The original suggestion: if the artwork is periodic it can be built as real geometry with nested `G4PVReplica` — MX17's 786 432-feature pattern costs **15 extra volumes and ~3 % CPU**, not 786 432 placements. It only affects backscatter off the board (the signal copper is downstream of both gas gaps), so it already ranked below P0.18. **But MX17's own plan has since concluded the opposite for their detector**: `RESPONSE_SIM_PLAN.md` §6 item 4 reads *"Do NOT model strips/pads/coverlay as Geant4 volumes — material budget is unchanged at the level that matters and the response chain owns that geometry."* That is a direct reversal of the advice we were given, from the people who tried it. **Before more effort goes in, someone has to decide which applies to P2.** The arguments do not transfer automatically: P2's drift gap is 3 mm against MX17's 30 mm, so a backscattered electron from the board is a much larger relative perturbation here, and P2's whole campaign question is a *fake-hit budget* dominated by wall conversions — the case MX17's "material budget is unchanged" claim is least likely to cover. Counter-argument for P2 is therefore real, but it is an argument, not a measurement: **the cheap resolution is to build it once, compare the conversion-layer budget against the homogenized slab, and keep the pattern only if the difference is visible.** *(Implemented 2026-08-07: 1280 annular-sector pads on the gerber-exact polar grid, 42 `G4PVReplica` rings, `--homogenized-readout` to switch back. 0 overlaps in both modes.)* **FIRST COMPARISON RUN, 2026-08-07 — split the question in two, as the implementing session proposed:** (a) **zoning** (one board-wide average → 10 radial bands) is *not* contested — the old F.Cu number was simply wrong, 0.937 against a measured 0.787, i.e. 25 % too much copper, most of it dumped where the artwork has almost none. (b) **patterning** (band-average sheet → real pads) is the part MX17 §6 item 4 argues about, and the measurements so far are: **muon ionization — no difference.** 2500 muons each: ⟨edepDrift⟩ 925 ± 28 eV patterned vs 937 ± 30 homogenized, medians matching to 0.4 eV; pad multiplicity 1.120 vs 1.117. (An apparent 8.6 % gap at 400 events was pure Landau statistics — a warning about small-sample comparisons here.) **Photon conversion budget — suggestive, not resolved.** 400 k γ at 60 keV each: total gas-ionization rate 3.500 ± 0.094 ×10⁻³ vs 3.378 ± 0.092 ×10⁻³ (0.9σ). But the difference is **confined to the one volume that changed**: `PCB_Cu_F` gives 1.025 ± 0.051 ×10⁻³ patterned against 0.918 ± 0.048 ×10⁻³ homogenized (**+12 %, 1.5σ**), while `Micromesh` (2.07×10⁻³, +0.1σ), `DriftGas` (+0.1σ) and every other layer are identical. A coherent story in the right place, at 1.5σ — which is exactly the level at which one should not conclude. **EXPLAINED, and the ~4 M-photon run is cancelled as uninformative.** The +12 % is not escape physics — it is **local areal density**. The bands are radial-only, so band 4 (r 294.95–354.94) carries fCu = 0.906 measured over *board ∩ annulus*, which includes the azimuthal margins of the wedge where there are no pads at all. The pad field itself is 0.978 of its annulus. The beam sits in the pad field, so the homogenized sheet simply has less copper under it. Quantitatively, for the `--beam-spread 11.4286` run above the beam spans bands 4 and 5 with weights 0.804/0.196 → homogenized fCu under the beam = 0.9081, against a patterned fill of 0.9781. **Predicted ratio 1.077 (+7.7 %), measured 1.117 ± 0.081 — 0.49σ apart.** Independently confirmed with muons: ⟨edepPadCu⟩ MPV ratio at a pad centre = 1.0959 over 6000 events, against 1/0.906 = 1.104 predicted. Thin-layer conversion probability is linear in areal density, so this fully accounts for the observation with no escape physics invoked. **And escape is bounded below the level that matters.** CSDA range in g/cm² is density-independent, and so is layer thickness in g/cm² (pad 0.0161, sheet 0.0146), so forward/backward escape fractions are nearly identical. Sideways escape into the etched grooves affects only perimeter × range / area = **0.35 %** of a pad (a 60 keV photoelectron has ~10 µm CSDA range in Cu on an 11.3 × 11.8 mm pad). Resolving a sub-percent effect at 3σ would need ~10⁹ photons — so escape is settled analytically and should not be simulated. **The corrected conclusion, which sharpens P0.19 rather than closing it:** radial-only banding is *too coarse where the beam is*. It dilutes pad copper into azimuthal margins the beam never illuminates, under-stating the local conversion rate by ~8–10 % at any pad centre and over-stating it in the margins. So: **board-integrated quantities agree** (total gas-ionization 0.9σ, pad multiplicity 1.120 vs 1.117, muon drift ionization identical), while **anything local to the beam spot differs by ~10 % with a known sign** — a systematic, not a fluctuation, and one the homogenized model cannot fix by re-measuring. Fixing it would require azimuthal zoning, at which point the pads have been re-implemented badly. That is a stronger argument for keeping the pattern than the original 1.5σ was. **Confirmed by a uniform-illumination run (2026-08-07):** with the beam spread over the whole wedge (500 k γ each, 250 mm spread), patterned and homogenized agree to **0.0σ** on `PCB_Cu_F` (7.700 vs 7.680 ×10⁻⁴) and −0.3σ on the mesh — exactly as the areal-density picture predicts, since the two models carry the same total copper mass by construction. So the effect is *purely* local: ~10 % where the beam sits on the pad field, zero when averaged over the board. **And the back copper is irrelevant either way:** `PCB_Cu_B` produced **0 conversions in 900 k photons** across both illumination patterns. It sits behind 18 µm Cu + 200 µm FR4, which a 60 keV photoelectron cannot traverse to reach the gas. So B.Cu staying a homogenized sheet (its 30 789 routed traces are not periodic and cannot be replicated) costs nothing for the fake budget — it matters only as material budget, where the zoned sheet has the mass right. |
| P0.20 | ⬜ **Resistive layer: confirm it is actually uniform** *(new 2026-08-07; MX17 §2.4 item 3)* | `DetectorConstruction.cc` places `ResistivePaste` as a **100 µm slab of full-density (1.4 g/cm³) paste** over the whole wedge — no coverage scaling, no structure. MX17's is now 515 discrete 550 µm ESL strips on a 0.8 mm pitch with real chamber gas in the grooves. This matters more than the pad pattern: the resist is the first solid the avalanche region sees and at 100 µm it is ~5× a P2 copper layer. **Needed input:** is the P2 resistive layer strips, a uniform DLC/paste sheet, or pads? If uniform, the current slab is right and only thickness/density need confirming — but that should be **stated, not assumed**. |
| P0.16 | 🟡 **Get the Dynamask pillar map — before any production run** *(new 2026-08-06, Dylan)* **Geant4 part done 2026-10-06:** `--pillars saclay` (default; V1 insulation mask, det1–det4, 3.80 %) or `cern` (det5, 4.90 %), placed in the amp gap from `include/P2Pillars.hh`, which `scripts/gerber/extract_pillars.py` generates with P2_basket_analysis' own `load_pillars`. **Still open: pillar dead spots in Stage B** (electrons landing on a pillar get no gain). | Fetch it from **`P2_Basket_Analysis`** (or wherever it lives) and put pillars in the geometry. We already have the *design* pattern from the CERN bulk mask (`P2_Mask2.gbr`: Ø 0.5 mm, pitch 2.000 mm exact, 41 366 pillars, **4.8 % of the amp gap**) and the material (**Dynamask** dry film, ρ ≈ 1.2–1.4 g/cm³ — not kapton/FR4); what we want is the map the *analysis* actually uses, so sim and data share one definition (same argument as the mapping revision, §10.6). Feeds: pillar dead spots in Stage B (electrons landing on a pillar are lost, no amplification there), the 4.8 % effective-gas correction, material budget. **Gating**: retrofitting pillars after a production run invalidates per-pad efficiency and the amp-gap scoring. Details: `NEEDED_INPUTS.md` addendum. |

Blocked on Alexandra (re-run affected points if answers move defaults): mylar
thicknesses/aluminisation, back-frame depth, frame opening/material,
overpressure/sag, mesh spec (wire diameter/pitch → transparency model),
pad-mapping revision.

## 4. Phase 1 — Geant4 sensitivity scans (MX17-style)

Goal: primaries produced in the drift volume (and elsewhere) per incident
particle, vs energy — the direct analog of the MX17 sensitivity plots, now
per gas and with provenance. Runs at baseline geometry (3 mm gap) plus the
gas list; **deliberately wider energy ranges than strictly needed**.

### 4.1 Electron scan

- **Energies** [MeV]: 1, 2, 5, 10, 20, 30, 50, 75, 100, **119**, 130, **144**,
  155, 175, 200 (log-ish below 30; dense around the elastic lines).
- **Angles**: 0°, 10°, 20°, 30°, 40° (full set at 30/119/155 MeV; {0°, 10°}
  elsewhere).
- **Position**: default mid-active (r = 355 mm); position axis deferred to a
  small dedicated scan (inner r = 150, outer r = 550, near-edge φ) at
  baseline energy only.
- **Statistics**: 10⁴/point general, 10⁵ at the baseline points (Landau
  tails, zero-cluster tail).
- **Observables**: nPrimDrift distribution (mean, width, P(0), P(<n));
  edep spectrum; cluster z-profile; δ-ray fraction reaching pads/amp gap;
  same for AmpGas (direct amp-gap ionization = anomalously large signals).

### 4.2 Photon scan

- **Energies** [keV]: 3, 5, 8, 10, 15, 20, 30, 40, **50**, 60, **80**, **100**,
  120, **150**, 200, 300, 500. (3–10 keV covers fluorescence/K-edge
  structure: Ar K 3.2 keV, Cu K 8.05 keV, Fe K 6.4 keV from the mesh; bold =
  the dominant background band.)
- **Angles**: 0°, 10°, 30°. **Statistics**: 10⁶–10⁷/point (with P0.5 the
  output stays small; most photons pass through untouched).
- **Observables**:
  - P(≥1 primary in drift gas) vs E — *the* photon sensitivity curve;
  - **conversion-layer budget — now the decision variable of the whole gas
    question** (§0, §1.1): fraction of gas-ionizing events whose electron
    originated in {drift gas, cathode mylar/Al, mesh, pad Cu, FR4, windows,
    front/back gas} — per gas, this separates "gas choice helps" from
    "wall floor". Run it **both** with the effective-density mesh slab and
    with the P0.13 wire geometry, and quote both; the analytic estimate
    (mesh 2.0×10⁻³ vs argon gas 2.3×10⁻⁴ per 60 keV photon) says this
    single number decides Ar vs Ne;
  - **per-event edep spectrum split by interaction class** (P0.12) — the
    plot this scan exists to produce. Overlay, per gas and per photon
    energy: gas-photoelectric / gas-Compton / fluorescence-reabsorption /
    wall-photoelectric / wall-Compton, against the electron-run MIP Landau
    from §4.1 on the same axis. **Rayleigh must be counted separately and
    excluded from "interactions"** — it deposits nothing;
  - nPrim spectrum *given* a conversion, split the same way (this is the
    fake-hit charge spectrum seed for Phase 2). Expect gas conversions at
    3–30× the MIP deposit and wall photoelectrons at ~3–5× — i.e. the wall
    population sits *inside* the MIP Landau tail, which is the pessimistic
    case for a charge cut and must be measured, not assumed;
  - **containment check**: fraction of the conversion electron's energy
    actually deposited in the gap vs its initial energy. §1.1 predicts
    Compton electrons are contained below ~80 keV while photoelectrons are
    not; if the sim disagrees, the range/geometry model is wrong;
  - escape-peak / fluorescence structure in Ar vs Ne mixes — including the
    **Cu-K 8.05 keV re-absorption chain** (§1.1), which needs P0.6's
    `deexcitationIgnoreCut` fix to exist at all;
  - **exit-particle inventory** (P0.4c): energy/direction spectra of
    photons and electrons leaving the wedge per incident photon — the
    convolution input for the correlated multi-wheel fake estimate
    (§5 step 5).

### 4.3 Muon validation runs — SPS test-beam anchor *(added 2026-08-05)*

An SPS test with **200 GeV muons** has just been taken (data analysis in
progress); `TESTBEAM_PLAN.md` is the full comparison plan. This subsection
adds the sim-side run points to Phase 1 so they ride the same
infrastructure and bookkeeping:

- **Particle/energy**: μ (sign per as-run beam), 200 GeV — CLI is already
  capable: `-p muon -e 200000` (energy flag takes MeV; `muon+` exists for
  μ⁺). **Normal incidence** = the existing default gun direction (+z
  pencil beam), aimed via `--gun-x/y` at the pad region illuminated in the
  test; no P0.3 angle work needed for this point. A small beam-spot/
  divergence option gets added once measured beam parameters arrive
  (`TESTBEAM_PLAN.md` §3).
- **Configurations**: (i) the **as-run test-beam configuration** (gas, HV,
  geometry deltas — from the `TESTBEAM_PLAN.md` §1 conditions checklist)
  for the direct data comparison; (ii) the **campaign reference gases**
  (§7.4 list) at baseline 3 mm, so the test-beam-tuned parameters can be
  transferred per gas and the tuned-vs-untuned shift quoted.
- **Statistics**: 10⁵ general; 10⁶ where efficiency-vs-threshold is
  compared (plateau inefficiency is a ≲1 % effect).
- **Observables**: same set as §4.1 (nPrim, edep, z-profile, δ-ray
  fraction, AmpGas direct ionization), plus through Stage B/C the
  data-comparable set: Landau MPV/width, pad multiplicity, efficiency vs
  threshold/HV (`TESTBEAM_PLAN.md` §4 has the observable↔parameter
  matrix).
- **Physics note**: 200 GeV μ sits on the relativistic-rise plateau —
  same MIP regime as our 30–160 MeV electrons in mm of gas, so the anchor
  transfers to the electron-efficiency side of the ROC nearly directly;
  it does *not* constrain the photon side. Keep muon radiative processes
  on (rare hard events populate the charge-spectrum tail seen in data).

### 4.4 Phase-1 deliverables

Sensitivity figure pair per gas (electron + photon curves overlaid across
gases), the conversion-layer stacked-bar figure, and a short note fixing the
nPrim→charge conventions for Phase 2. Also the PAI-vs-default-EM comparison
(P0.6) at 119 MeV / 3 mm / ArIso + NeIso.

## 5. Phase 2 — response chain and ADC discrimination

Apply Stage B+C to Phase-1 baseline samples (3 mm, all gases; 119 MeV e⁻ at
10° vs 50/80/100/150 keV γ):

1. Gas tables per gas (P0.10); pick the drift-field operating point per gas
   (near velocity plateau where one exists; document choice — this also
   yields the **drift-time span** = coincidence-window input).
2. Gain: set per-gas mesh voltage for a common reference gain (e.g. 10⁴,
   anchored per §2); record the voltage — operational headroom matters for
   stability/discharge arguments later.
3. Produce per-event **pad charge maps**; per event: max-pad charge, summed
   charge, pad multiplicity, hit-pad pattern length (a crude "trackness"
   proxy for oblique electrons). Note the discrimination is **topological as
   much as total-charge**: a 6–8 keV fluorescence photoabsorption is a
   point-like ~230–300 e⁻ deposit on 1–2 pads, while a MIP crossing 3 mm
   leaves ~30–50 e⁻ *spread along the track* — so diffusion and pad sharing
   must be modeled honestly, and both per-pad and per-event
   charge cuts should be scanned. High-energy wall photoelectrons ranging
   through the gas are the hard case (electron-like charge); flag their
   fraction separately. Expectation check (Dylan, 2026-08-05): at 10° a
   track averages only **~1.1 pad hits**, so topology is a *secondary*
   discriminant at the nominal angle — quantify what it adds, but the
   working assumption is charge deposition + 3-layer coincidence carry the
   weight. *(2026-08-06)* Clustering of the ~10 % of hits that do share
   charge is an **offline geometric step** (`vmm/nl_map.py`
   `geometric_neighbors`), run on pads that each passed threshold; the
   **VMM neighbor logic is off in the baseline** and is a separate,
   channel-space model (§2). Report pad multiplicity with the NL state
   stated — the two are not comparable numbers.
   **3a. Edep → charge proportionality audit** *(new 2026-08-05; the "does
   the deposited energy actually become ADC" question, full list in
   `research/PHOTON_DISCRIMINATION_NOTES.md` §5)*. Before any ROC is
   believed, quantify each proportionality breaker at the working point and
   state which ones are deposit-dependent (i.e. distort the discrimination)
   rather than a constant scale factor:
   - **z-dependent partial gain in the amp gap** —
     G(z) ≈ G_full^((z_mesh−z)/d_amp), four decades within one volume, and
     it governs the pad-Cu photoelectron population specifically. Modelling
     these at flat full gain is qualitatively wrong, not just imprecise.
   - **space-charge gain suppression on dense deposits** — a contained
     8 keV blob is ~300 primaries in ~100 µm; at gain 10⁴ that approaches
     the Raether limit and the gain sags. This **compresses exactly the
     separation the discrimination relies on**, and it is also the spark
     mechanism. No measured curve exists for our geometry ⇒ bracket it and
     flag any conclusion that depends on the compressed region.
   - **ballistic deficit** (§5 step 6) — breaks proportionality in our
     favour, but not against wall photoelectrons, which are track-like in
     time too.
   - **charge sharing + per-pad threshold**, **ADC saturation**, **pillars
     (4.8 % dead area)**, **mesh transparency**, **attachment** — all
     smaller; quantify once, then carry as a fixed systematic.
   - **Penning transfer / effective W** — gas-dependent, and it silently
     mis-scales Ne against Ar if a single tabulated W per gas is used.
     Also fix the `SteppingAction` W treatment: `floor(edep/W)` + uniform
     remainder gives Bernoulli rather than Fano fluctuations, which
     distorts the *width* the ROC integrates over.
   Deliverable: a one-page waterfall from ⟨edep⟩ to ⟨PDO⟩ per gas, with the
   deposit-dependent terms separated from the constant ones.
4. **ROC curves**: electron efficiency vs photon acceptance as a per-pad
   (and per-event max-pad) **charge window** scans, per gas — lower cut
   against noise and partial-clip deposits, **upper cut** against
   conversions (a gas conversion in the band deposits 3–30× the MIP charge
   — see §1.1; the "10–100×" figure applies only to fully contained few-keV
   photoabsorption such as ⁵⁵Fe — so a lower threshold alone cannot reject
   it; the ε_e price of the upper cut is the Landau/δ-ray tail, which the
   sim gives directly). **Break the ROC out by conversion class**: the
   dominant wall-photoelectron population lands at ~3–5× MIP, inside the
   Landau tail, and may be largely irreducible by charge alone — if so,
   say so plainly and let the coincidence carry it.
   Headline FOM: **ε_e at 90/99/99.9 % single-hit photon rejection**, and
   the window in fC (and in primary-electron equivalents) where it sits.
5. **Coincidence extrapolation** (analysis-only): with per-layer photon hit
   probability p_γ(E, threshold) and the experiment's 15–20 kHz/pad γ rate
   and drift-time window, estimate accidental 3-layer fake-track rates vs
   threshold — the bridge from single-wedge sim to the online-tracking
   question. Pure arithmetic once Phase 2 numbers exist. Add the
   **correlated-fake bound** from the P0.4c exit-particle record
   (Compton punch-through convolved wheel-to-wheel) — accidentals and
   correlated fakes scale differently with the coincidence window, so
   report both. **The window has a floor set by the per-hit time
   resolution** *(2026-08-06)*: it cannot be tightened below a few σ_t
   without losing real triples, and σ_t is 12 ns (Ar mixes) vs 25 ns
   (Ne/CO₂/Iso) — a 2× difference in window, i.e. **4× in accidental
   doubles and 8× in triples**, which is larger than the Ar-vs-Ne
   difference in photon conversion probability. Take σ_t per gas from
   `research/TIME_RESOLUTION_NOTES.md` §0 and quote the window as
   max(k·σ_t, drift-span term).
6. **Time-structure discriminants** *(blue-sky pass 2026-08-05 — details
   and the ⁵⁵Fe-vs-⁹⁰Sr bench proposal in `research/TIMING_PSD_NOTES.md`)*:
   a track's charge arrives spread over the full drift-time span
   (~60–110 ns depending on gas) while a gas conversion is a point deposit
   arriving at one time. Scan peaking time 25–200 ns in the T1 emulator
   (short t_p suppresses track PDO but not point-deposit PDO — it *widens*
   the charge-window separation, at an ENC cost that the noise data must
   adjudicate), and use the clustering of real-track TDOs to tighten the
   3-layer coincidence window below the full drift span (accidentals fall
   quadratically with the window).
   **Price side now measured** *(2026-08-06,
   `research/TIME_RESOLUTION_NOTES.md` §3)*: at a fixed 2 fC threshold the
   ballistic deficit costs MIP efficiency 99.4 % → 96.7 % → **77.8 %** going
   t_p = 100 → 50 → 25 ns in Ar/CO₂/Iso, and 92.6 % → 78.1 % → **42.1 %** in
   Ne/CH₄. Any short-peaking scheme must either lower the threshold in step
   or pay that ε_e directly — fold this into the handle-1 ROC before
   proposing it.

7. **Time resolution per pad hit** *(new step, 2026-08-06)*. Deliverable:
   σ_t(gas, gap, t_p, threshold, ENC) with the contribution budget, both raw
   and time-walk-corrected, plus the predicted (PDO, TDO) correlation — the
   quantity to compare against the SPS muon data. First pass is already done
   with a standalone toy (`vmm/time_resolution.py`, no Geant4/Stage B
   needed): **σ_t ≈ 10–13 ns in argon mixtures, 15–25 ns in neon mixtures**,
   dominated by primary-ionization statistics as σ_t ≈ (1.0–1.5)/(n_p·v_d).
   Re-run through the full chain once Stage B exists and once Magboltz v_d
   replaces the placeholder drift velocities (P0.10) — σ_t ∝ 1/v_d, so that
   is the leading input uncertainty. Feeds step 5 (coincidence window) and
   `TESTBEAM_PLAN.md` §2.6.

Validation inside Phase 2: a handful of full Garfield++ AvalancheMC/
microscopic events vs the sampler; sensitivity of ROC to Polya θ, ε_mesh,
and gain ±50 %. **Data anchoring**: once the SPS muon comparison
(`TESTBEAM_PLAN.md`) produces `tb_tuned_params.json` (gain anchor, θ,
ε_mesh, measured ENC), re-derive the Phase-2 headline numbers with tuned
parameters and quote tuned-vs-untuned as the modeling systematic.

### 5a. Source-validation predictions — bench anchor for the photon side

The muon test beam anchors only the electron/MIP side; the photon side
gets its bench anchor from lab sources, which map directly onto the
background band: **⁵⁵Fe 5.9 keV** (gain anchor *and* the canonical
point-deposit reference — our preferred source), **²⁴¹Am 59.5 keV**,
**¹⁰⁹Cd 88 keV**, **⁵⁷Co 122 keV**, plus **⁹⁰Sr/⁹⁰Y β** as the track-like
reference (spectrum CSV already in `sr90_calibration/`). Simulate each
source on the prototype geometry (P0.11 source mode), per gas: predicted
pad-charge/PDO spectra, fake-hit probability above the working charge
window, escape-peak and fluorescence structure. Deliverable: one
predicted-vs-measured figure per source; generate the predictions *before*
the bench data lands so the comparison stays blind-ish. The same source
set doubles as the Ne-mixture gain scan of §7.2 once the mixer exists.

## 6. Phase 3 — drift gap × gas matrix

The decision matrix. Axes:

- **Drift gap**: 1.0, 1.5, 2.0, 2.5, 3.0, 3.5, 4.0 mm (user-specified grid).
- **Gas**: the §7.4 list — A1–A3, N1–N8 + N10 (all ~13 through Phase 1 +
  Magboltz; down-select to ~8 for the full matrix; N9 ALICE-mix contingent
  on its drift time).
- **Kinematics subset**: e⁻ {30, 119, 155} MeV × {10°} (+ {0°, 30°} at
  119 MeV); γ {50, 80, 100, 150} keV × {10°}.
- Geant4 runs: 7 gaps × ~8 gases × ~9 kinematic points ≈ **500 runs**
  (10⁴–10⁵ e⁻ / 10⁶–10⁷ γ each) — routine HTCondor scale given the thin
  detector. Stage B/C re-runs are cheap (Python over cluster files).

Deliverables: the (gap, gas) heatmaps of — ε_e at fixed γ rejection; P₀
floor; pad multiplicity; drift-time span; **per-hit time resolution σ_t**
(2026-08-06 — cheap to add, and it feeds the coincidence window of §5 step 5
where it competes with the gas's photon-rejection difference); required mesh
voltage for reference gain. Plus a recommendation memo: operating point(s) to carry into
prototype tests, with the flammability/premix constraints from §7 applied.

## 7. Gas candidates — physics, flammability, procurement

*(Research pass done 2026-08-05; full citations in
`research/GAS_NOTES.md`. Physics numbers already merged into §1.)*

### 7.1 Flammability — the binding constraint (ISO 10156:2017)

Non-flammable in air *in any proportion* iff Σ(A′ᵢ/Tcᵢ) ≤ 1 after converting
inerts to N₂-equivalents (Kk: **Ar 0.55, Ne 0.7**, CO₂ 1.5, N₂ 1; Tci:
**iC₄H₁₀ 3.4 %, C₂H₆ 4.5 %, CH₄ 8.7 %**). Computed limits for us:

- binary **Ar/iC₄H₁₀: ≤ ~1.9 %** iso; **Ne/iC₄H₁₀: ≤ ~2.4 %** (Ne is a
  slightly better inertant than Ar); Ne/C₂H₆ ≤ ~3.2 %; Ne/CH₄ ≤ ~6.2 %.
- **All our ≥5 % isobutane candidates are flammable**, full stop — usable
  (COMPASS ran flammable Ne/C₂H₆/CF₄ for 20 years) but they buy sniffers,
  zoning and interlocks at MESA.
- CO₂ rescues ternaries: NSW Ar/CO₂/iC₄H₁₀ 93/5/2 passes at ratio 0.97
  (barely — the folkloric "<3 % iso is non-flammable" traces to the
  superseded 1996 edition); **Ne/CO₂/Iso 95/3/2 passes at 0.83, more margin
  than NSW itself.** ISO also allows certifying a marginal mix by spark-tube
  test. Governing CERN rule: Flammable Gas Safety Code G.
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

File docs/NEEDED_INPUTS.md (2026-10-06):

# Needed external inputs — the register of what we are guessing

**Written:** 2026-08-05. One place for everything the simulation currently
*assumes* because nobody has given us the number, ordered by how much the
answer would move a campaign conclusion. Each item says what we assume now,
why it matters quantitatively, and what specifically to ask for.

Companion docs: `P2_MODEL.md` (geometry assumptions — Alexandra's review),
`testbeam/TB_CONDITIONS.md` (test-beam as-run conditions),
`research/PHOTON_DISCRIMINATION_NOTES.md` (photon physics),
`SIM_CAMPAIGN_PLAN.md` (the campaign these feed).

Legend: ⬜ needed · 🟡 partially known · ✅ have it.

---

## 1. ⬜ Spatial and angular distribution of the signal electrons

**Raised by Dylan, 2026-08-05: "I don't know the spatial distribution of the
electrons nor the X-ray background, and I assume that matters."** It does,
and more than the campaign currently accounts for.
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

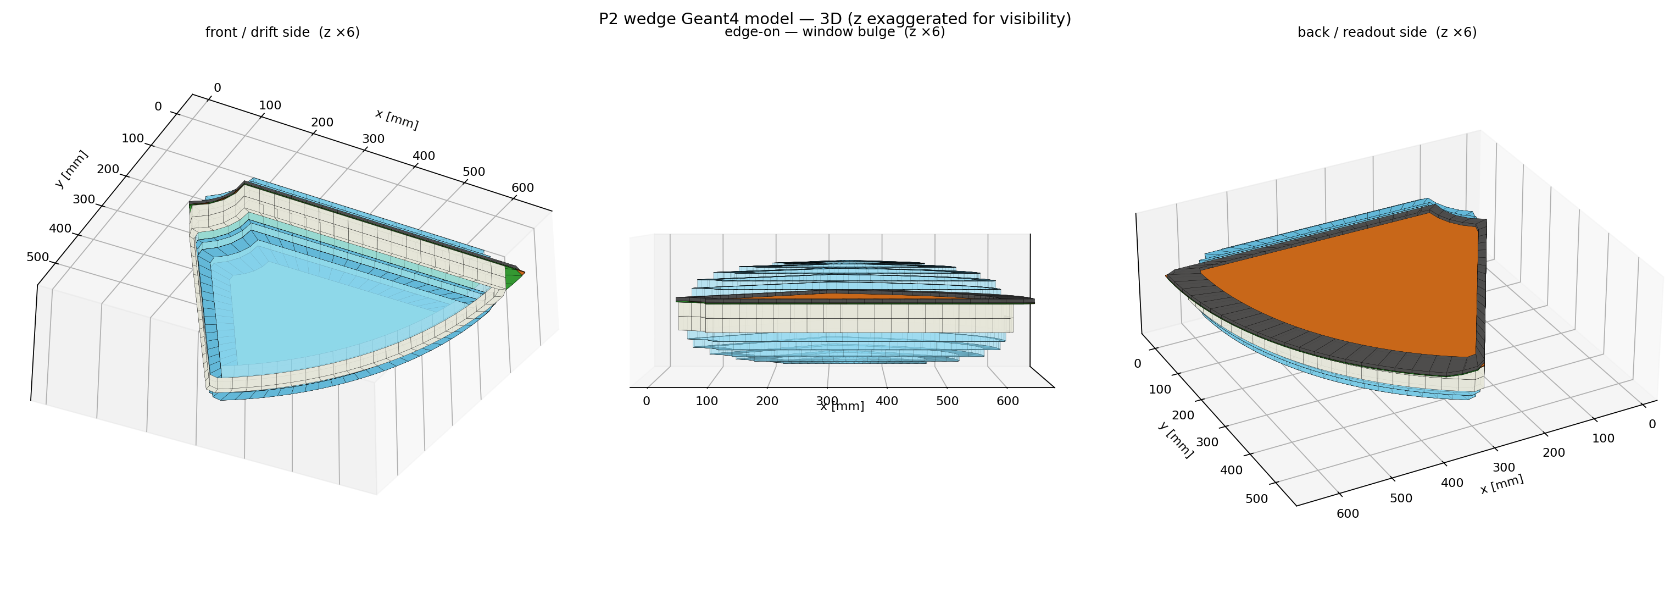
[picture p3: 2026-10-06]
docs/figures/p2_3d_overview.png

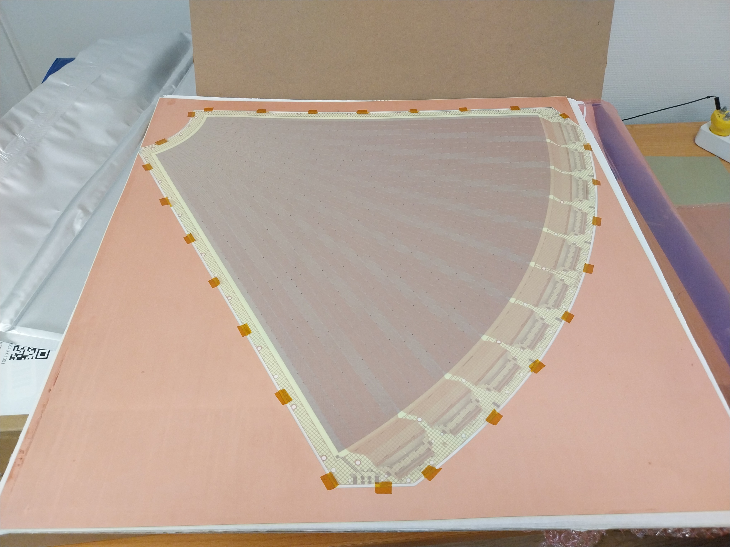
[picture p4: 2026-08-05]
design/gerbers/P2_BASKET_Apr26/BOT.jpg

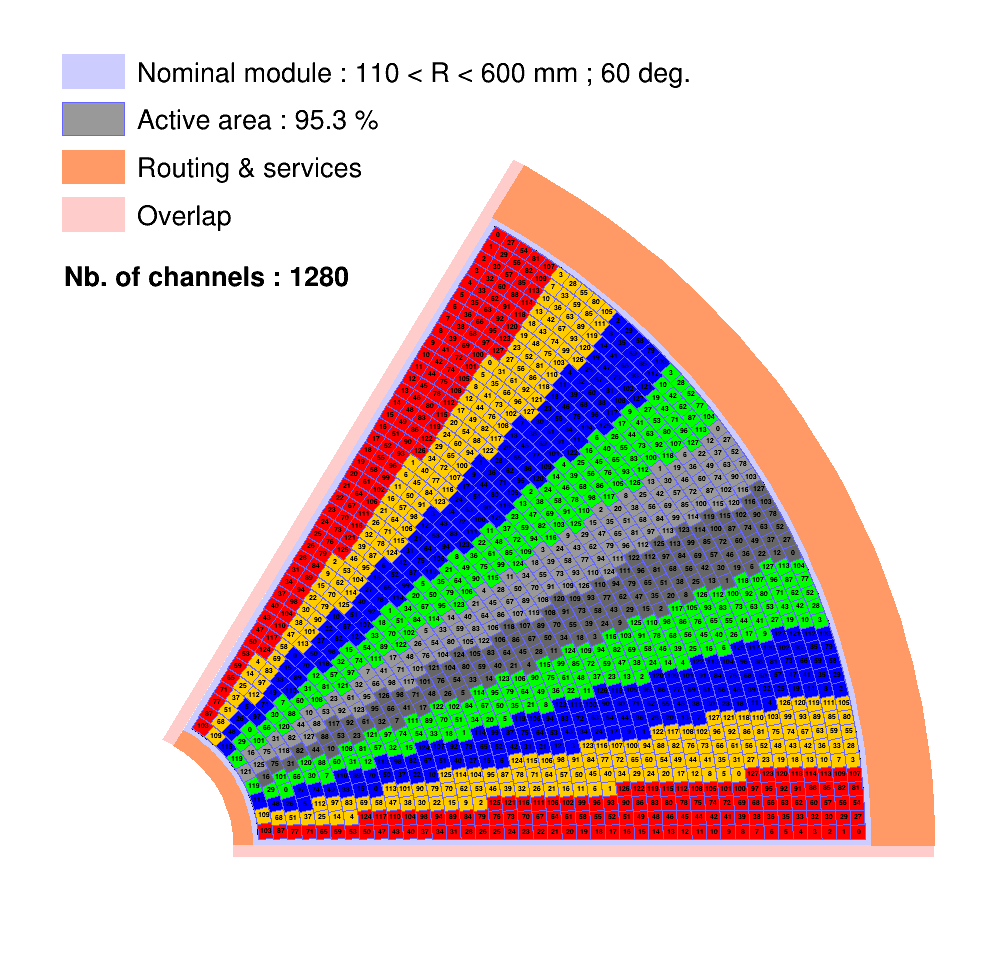
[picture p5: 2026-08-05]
design/mapping/module_equalized.png

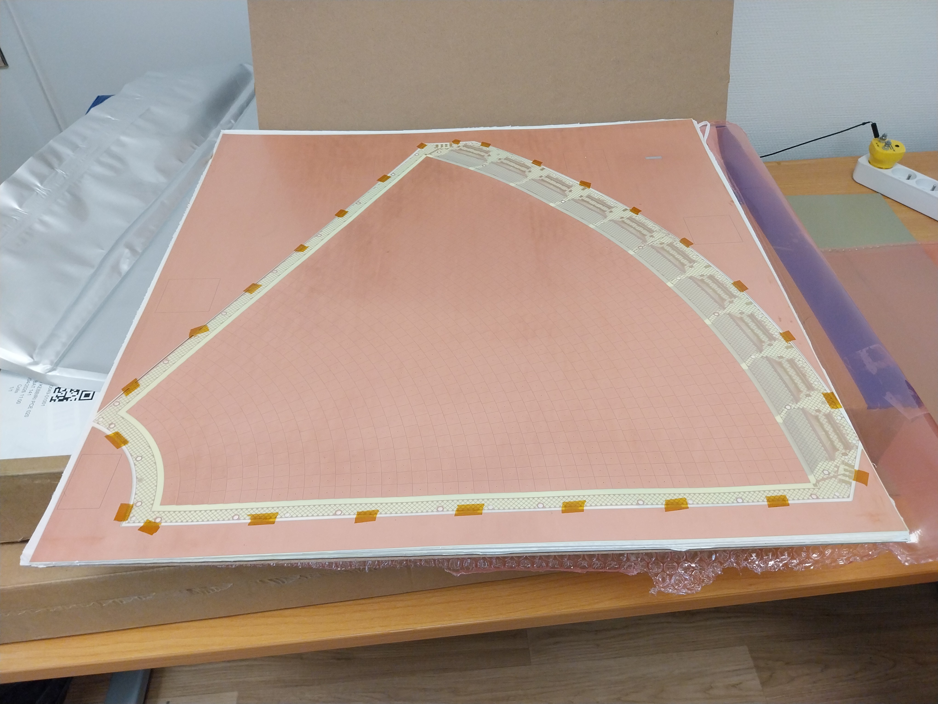
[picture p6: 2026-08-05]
design/gerbers/P2_BASKET_Apr26/TOP.jpg

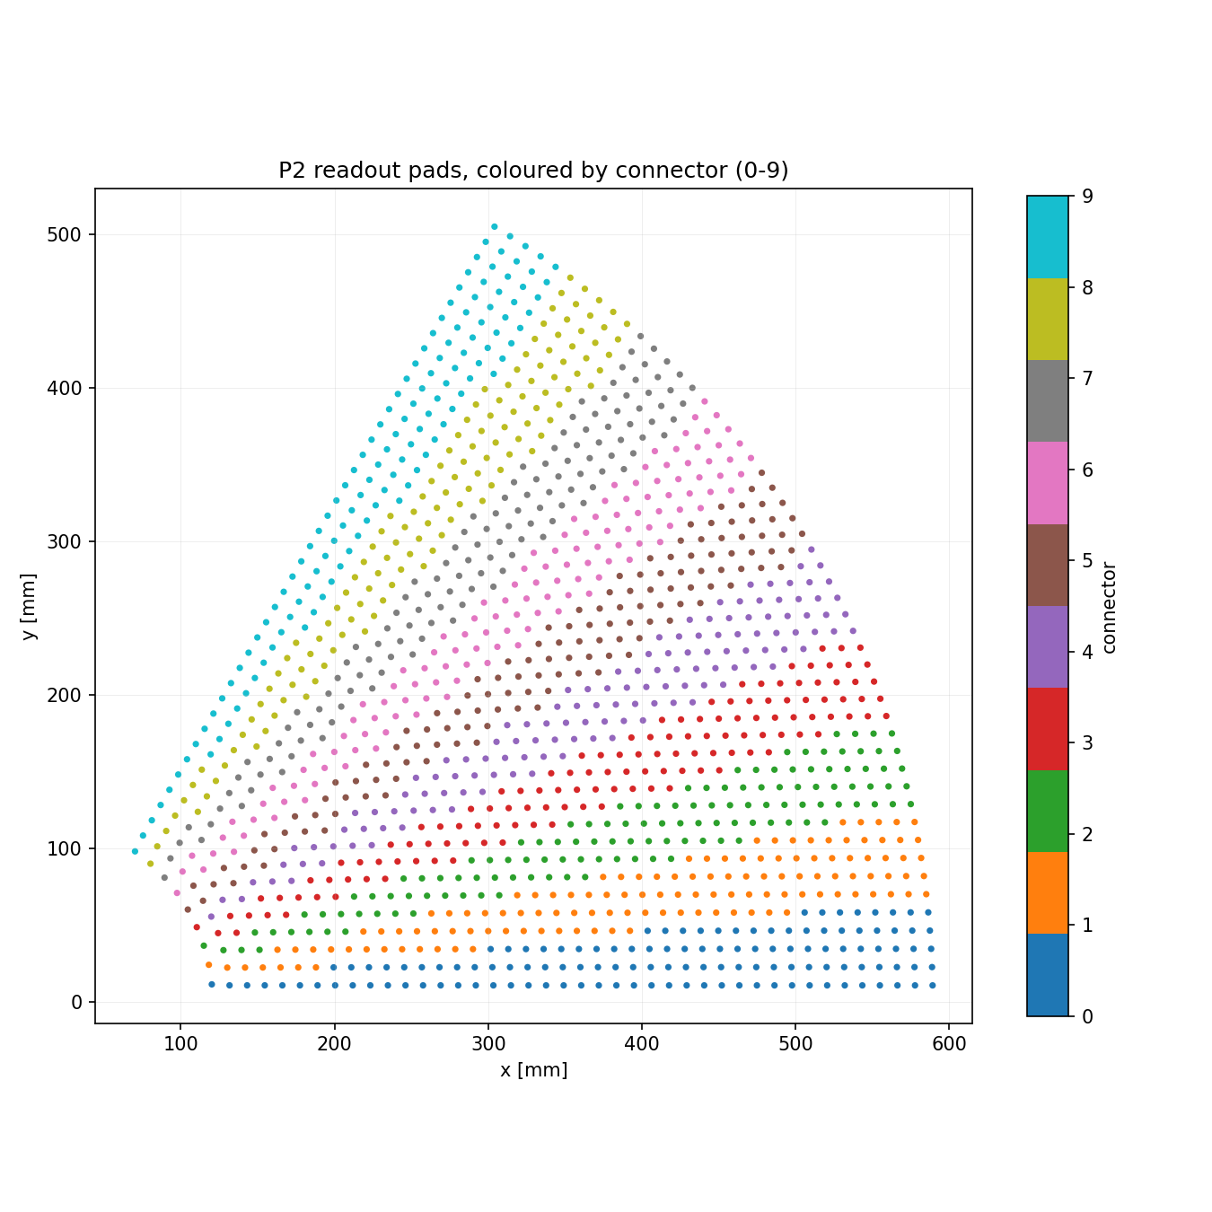
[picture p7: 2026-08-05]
docs/figures/p2_readout_padmap.png

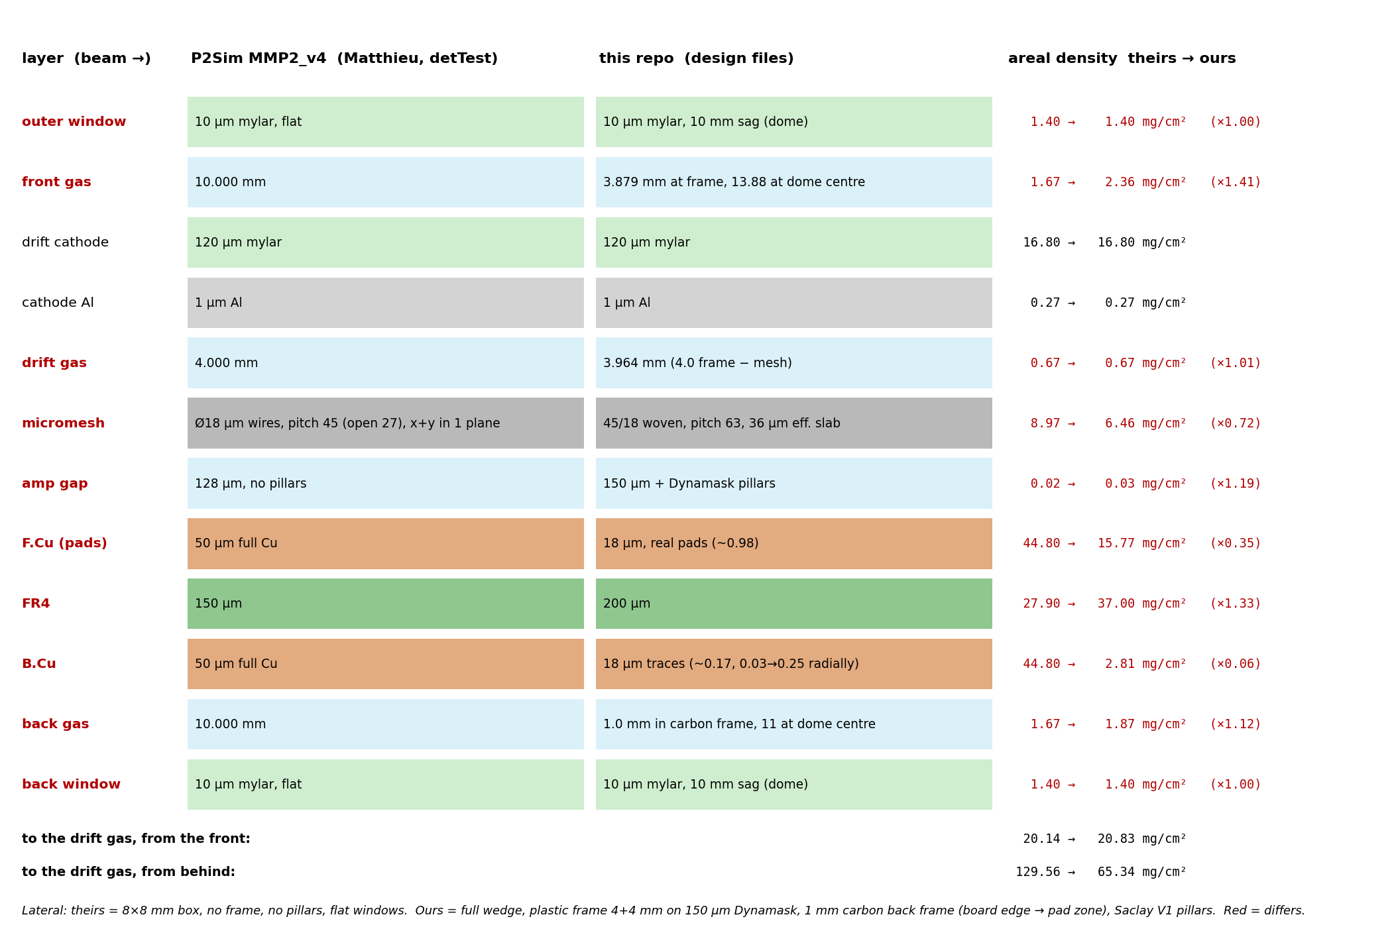
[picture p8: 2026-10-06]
docs/figures/p2_stack_vs_p2sim.png

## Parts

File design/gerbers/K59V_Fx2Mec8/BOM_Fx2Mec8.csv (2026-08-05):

Reference | Value | Datasheet | Footprint | Qty | DNP
FID1,FID2,FID3,FID4,FID5,FID6 | Fiducial | ~ | Library-P2-FEAB:MIRE_CMS-P2-FEAB | 6
HC_1,HC_2,HC_3,HC_4,HM1_1,HM1_2,HM2_1,HM2_2 | MountingHole_Pad | ~ | MountingHole:MountingHole_3.2mm_M3_Pad | 8
J2 | FX20-140S-0.5SH_P2 | https://www.hirose.com/en/product/document?clcode=CL0570-1006-4-10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 | Fx20_140S:FX20140S05SV1510_P2_FEAB_FINAL | 1
JM_1,JM_2 | MEC8-135-02-X-D-RA1 |  | Mec8:SAMTEC_MEC8-135-02-X-D-RA1 | 2
TP_1 | TestPoint | ~ | TestPoint:TestPoint_THTPad_D1.0mm_Drill0.5mm | 1

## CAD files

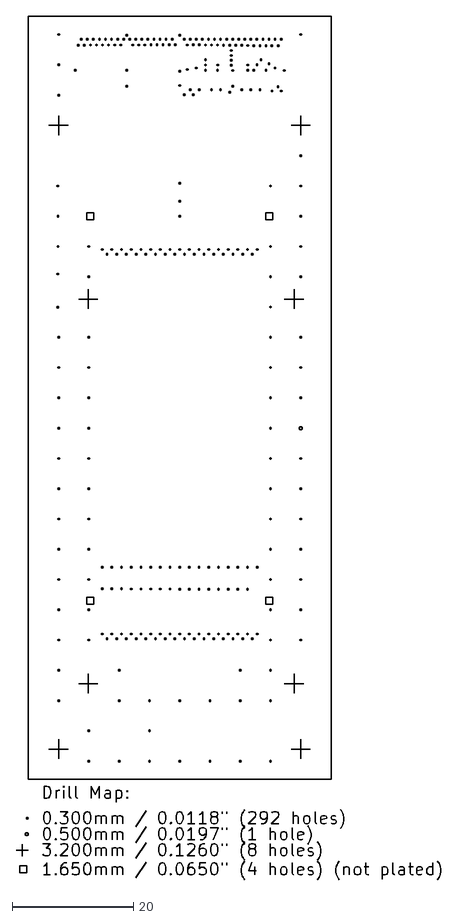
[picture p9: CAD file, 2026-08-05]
design/gerbers/K59V_Fx2Mec8/NCDrill/Fx2Mec8-drl_map.dxf
70.1 x 142.6

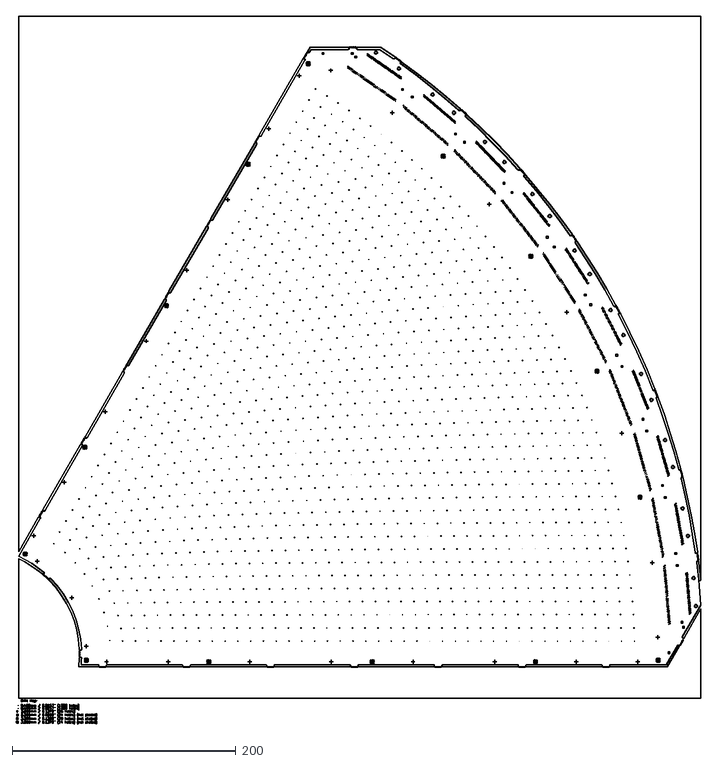
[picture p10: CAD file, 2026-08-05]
design/gerbers/P2_BASKET_Apr26/NCDrill/P2_BASKET-drl_map.dxf
612.1 x 633.0

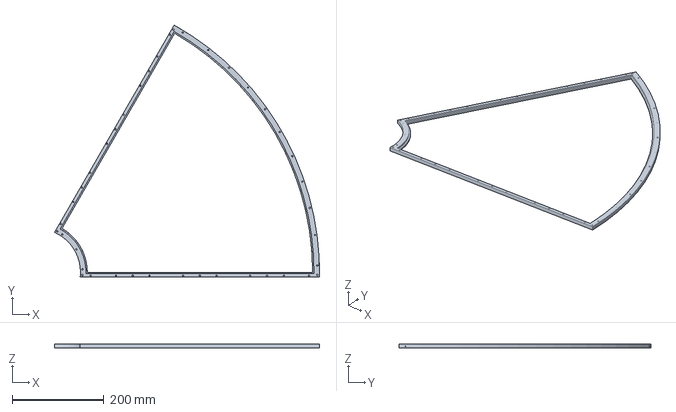
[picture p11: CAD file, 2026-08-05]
design/mechanical/P2_Frame_V2_4mm.stp
576.4 x 547.5 x 8.00 mm

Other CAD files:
design/mechanical/P2_Frame_V1_3mm.stp

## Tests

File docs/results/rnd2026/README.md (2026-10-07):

# rnd2026 — first look (Geant4 only)

Batch: `submit_condor_p2.py --scan rnd2026`, HTCondor cluster 12403408,
commit f643863, 106 jobs, 80.44 M events, `/eos/user/a/akallits/p2_sim/rnd2026`.
Analysis: `scripts/analysis/rnd2026_photons_electrons.py` (run on lxplus).

Primary-ionization level only: "detected" = ≥ 1 primary electron in the drift
gas; observable = energy deposited in the drift gas. No gain, threshold or
electronics yet (needs the Magboltz tables and Stage B/C).

| result | 3.96 mm drift gas (4 mm frame) |
|---|---|
| P(detect) per photon, 40–100 keV | Ar 2.5 → 0.6 × 10⁻³ · Ne 1.5 → 0.45 × 10⁻³ |
| Ar / Ne | 1.7× at 40 keV, 1.3× at 100 keV — wall conversions (mostly the mesh) dominate |
| isobutane 5 → 10 % | no change in P(detect) or in the e⁻ deposit |
| 5 mm drift gas | P(detect) +5–15 %, e⁻ deposit +40 % |
| e⁻ 100 MeV most probable deposit | Ar 0.8 keV · Ne 0.4 keV |
| detected photons | median 6–10 keV; mesh Fe/Ni K lines (6.4 / 7.5 keV) + full absorption |
| upper cut at 99 % e⁻ eff. | Ar 9–13 keV, Ne 6–8 keV → removes 35–55 % (Ar), 40–70 % (Ne) of detected photons |
| upper cut at 95 % e⁻ eff. | 3–5 keV → removes 70–93 % |
| MM0 rate, P2Sim flux 10–150 keV | Ar 79 → 41 MHz · Ne 37 → 20 MHz after the 99 % cut (whole layer) |

Files: `photon_summary.csv`, `electron_summary.csv`, `fold_p2sim.csv`, `fig1–4`.

Caveats
- Gas vs wall is split on `convVolume`. Up to f643863 `interactionClass` tagged
  a soft (< 20 keV) beam photon absorbed in the gas as fluorescence (fixed in
  `EventAction.cc` after this batch).
- 10–150 keV covers 84 % of the MM0 flux; the softer part is not included yet.
- The 99 % electron cut rests on 10⁴ electrons per point (±~1 keV).

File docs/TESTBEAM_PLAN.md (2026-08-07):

# SPS muon test beam ↔ simulation comparison — plan

**Written:** 2026-08-05. Status: **planning — test-beam data analysis in
progress (external), sim runs gated with the campaign** (geometry review,
`SIM_CAMPAIGN_PLAN.md` §10.1). Companion docs: `SIM_CAMPAIGN_PLAN.md`
(campaign this plan feeds into; muon validation run point is its §4.3),
`P2_MODEL.md` (as-built geometry), `vmm/README.md` (VMM3a emulator).

> **Follow-up handoff (2026-08-05):** Dylan does not have the logbook or
> run data — **Alexandra owns the follow-up**. The concrete ask is one
> document: fill in **`testbeam/TB_CONDITIONS.md`** (a fill-in template of
> the §1 checklist, every field marked ⬜ NEEDED, annotated with the sim
> setting each answer feeds) plus the run manifest
> `testbeam/tb_run_manifest.csv`, and agree the §2 data-deliverable format
> with whoever analyzes. Everything in §3–§7 is blocked on that; nothing
> else here needs action until the answers land.

---

## 0. Purpose

A test with **200 GeV muons at SPS** just finished (2026-08); the data is
being analyzed. This is the first real-world measurement of the detector the
campaign simulates, and it lands exactly on the campaign's weakest spots:
the **absolute gain scale, Polya θ, noise/threshold model, and
diffusion/pad-sharing** are currently literature values and assumptions
(campaign risk §10.2). The plan here: replicate the as-run test-beam
conditions in the full Stage A→B→C chain, compare a fixed set of
observables, tune the small set of free parameters, and propagate the tuned
model back into the campaign's headline numbers.

What the muon data anchors — and what it can't:

- 200 GeV muons are clean MIPs on the relativistic-rise plateau, same
  specific-ionization regime as the 30–160 MeV MESA electrons in mm of gas
  (both β≈1; muons just don't shower and barely scatter). So the test beam
  anchors the **electron-signal side** of the campaign's ROC almost
  directly: charge spectrum, cluster size, efficiency vs threshold.
- It says **nothing about the photon side** (50–150 keV rejection) — that
  stays simulation + lab sources (⁵⁵Fe).
- If the test ran an Ar-based gas, the anchor transfers to Ne mixtures only
  through the assumed Penning r — the prototype ⁵⁵Fe/⁹⁰Sr gain scan in Ne
  (campaign §7.2) is still needed.

## 1. Step 0 — pin down the as-run conditions (blocking everything else)

Nothing can be simulated faithfully until these are collected from the
test-beam team / logbook / DAQ configs. **The fill-in template exists:
`testbeam/TB_CONDITIONS.md`** (every item below expanded into ⬜ NEEDED
fields, each annotated with the sim setting it feeds), with the
machine-readable **run manifest** `testbeam/tb_run_manifest.csv` beside it
(one row per run: runID, HV_mesh, HV_drift, gas, threshold, angle,
position, N_triggers, good-flag, remarks) — same no-un-manifested-runs
discipline as campaign §9. **Assigned to Alexandra** (holds logbook + run
data).

| # | item | why it matters |
|---|---|---|
| T0.1 | Detector(s) under test: which wedge/prototype, serial, any geometry deltas vs `P2_MODEL.md` (drift gap, mesh, window stack, no-bulge if run near atmospheric) | Stage A geometry |
| T0.2 | Gas: mixture, purity, flow, P/T logs over the run period | Stage A gas + Magboltz table; P/T drift is a few-% gain effect |
| T0.3 | HV points: mesh + drift voltages, and whether an **HV scan** was taken (the single most valuable dataset for gain anchoring) | gain calibration §4 |
| T0.4 | Readout: VMM3a hybrids? peaking time, gain [mV/fC], threshold settings (DAC + measured fC), neighbor logic on/off, which mapping revision | Stage C emulator settings; the mapping revision decides the **readout order** (only 11/1280 channels agree between revisions) and therefore what NL reads and how channel-level comparisons are made |
| T0.4b | **Timing configuration** *(added 2026-08-06)*: TDO mode (threshold-crossing vs time-at-peak), TAC ramp (60/100/350/650 ns), BC clock, per-channel time calibration applied? | the σ_t comparison (§2.6) is undefined without these — `research/TIME_RESOLUTION_NOTES.md` §1 |
| T0.5 | Trigger + tracking: telescope type/resolution, scintillator coincidence, geometry of reference detectors, **and the resolution of whatever defines t = 0** | which efficiency/residual analyses are possible; σ²_measured = σ²_pad + σ²_reference, so σ_reference is mandatory for the timing comparison |
| T0.6 | Beam: μ⁺ or μ⁻, momentum spread, spot size/divergence, incidence angle(s), which pad regions illuminated (positions scanned?) | gun config; `--gun-x/y` aim points |
| T0.7 | Known pathologies: dead/noisy channels, HV trips, saturation | comparison masks |
| T0.8 | Data format + where it lives; who is analyzing what; agreement on the deliverable format of §2 | avoids duplicated/mismatched analysis |

## 2. Data-side deliverables (to request from / agree with the analyzers)

Per run (or per HV point), as histograms (ROOT/npz) **plus one summary CSV
row** so the sim comparison is scriptable:

1. **Pedestal/noise per channel** → ENC in fC at the real pad capacitance
   (75–170 pF) — direct input to the Stage C threshold model, replacing the
   estimated several-thousand-e⁻ ENC.
   **Ask for dedicated pedestal runs, and for the covariance — not just the
   per-channel σ** *(MX17, 2026-08-06 — `HANDOFF_MX17_RESPONSE.md` §2.4)*.
   MX17 derives, from dedicated pedestal acquisitions on DREAM, both the
   per-channel σ **and the common-mode covariance** between channels; they
   then inject correlated noise in simulation and let the analysis do common-
   mode subtraction exactly as it does on data. The approach transfers
   directly to a VMM bench. Why it matters here: a per-channel σ alone
   implies *independent* noise, and independent noise averages down across a
   cluster while common-mode does not — so a threshold model built on σ alone
   will be optimistic about the fake-hit rate at low threshold, which is
   precisely the regime the efficiency/ROC argument lives in. Requesting a
   pedestal run is cheap and can be done without beam.
2. **Cluster charge spectrum** (Landau): MPV + width, vs HV if scanned.
3. **Cluster size / pad multiplicity** distributions, **with the
   neighbor-logic state noted** — NL-on and NL-off multiplicities are not
   comparable numbers, and on this pad plane NL adds *channel* neighbors
   that are only sometimes physical neighbors (`vmm/README.md` §3.1). We
   expect ~1.1 pads/track at normal-ish incidence with NL off; a
   significantly larger measured value with NL off would mean the transverse
   spread (diffusion + track projection) is bigger than modeled, which
   propagates straight into the ROC.
4. **Efficiency vs threshold** (offline threshold scan on the data) and
   **vs HV** — needs the telescope or a layer-tag; the direct analog of the
   campaign's Phase-2 ε_e.
5. Spatial residuals vs telescope (if available) — secondary for us, but
   validates diffusion + pad pitch.
6. **Timing — promoted to a headline comparison (2026-08-06).** We now have
   a prediction to test: per-pad σ_t ≈ **10–13 ns in argon mixtures**,
   15–25 ns in neon mixtures, dominated by primary-ionization statistics
   (`research/TIME_RESOLUTION_NOTES.md`). Requested, per run:
   - the **TDO residual distribution vs the reference time**, delivered
     **both raw and time-walk-corrected** (we predict both; a σ quoted
     without saying which is not comparable), with σ_reference stated;
   - the **(PDO, TDO) two-dimensional distribution**, not just projections —
     that plot *is* the time-walk curve and is the sharpest single test of
     the Stage B+C chain (its slope tests drift velocity and shaper model
     together);
   - **σ_t vs peaking time**, if more than one t_p was run (free model check,
     see §2.9);
   - the drift-time *span* (as before) → Magboltz drift-velocity check;
   - per-channel time offsets: calibrated out or not? An uncalibrated
     channel-to-channel spread inflates the pooled σ and reads as poor
     detector resolution.
   Feeds the tightened coincidence window (`research/TIMING_PSD_NOTES.md`
   §4, campaign §5 step 5), whose floor is a few σ_t.
7. Stability: MPV vs time and vs P/T → validates (or motivates) a P/T gain
   correction term.
8. Rate of anomalously large signals (δ-rays, showers from the occasional
   radiative muon event) — tail of the charge spectrum, not just MPV.
9. *(added 2026-08-05)* If any runs were taken at **more than one peaking
   time** (T0.4): PDO spectra per t_p — the MIP MPV vs t_p is the
   ballistic-deficit curve that the pulse-shape-discrimination idea rides
   on (`research/TIMING_PSD_NOTES.md` §2); flag which t_p settings exist
   even if no scan was intended.

## 3. Sim-side — replicate the test beam

Works today in `p2` mode with minor additions; run **after** P0.1 (gas
mass-fraction bug) and the Phase-0 output upgrades, on the frozen geometry.

- **Beam**: `-p muon -e 200000` (CLI takes MeV; `mu-` vs `mu+` per T0.6 —
  add `muon+` if that's what ran). The default gun is already **normal
  incidence** (+z pencil beam); aim with `--gun-x/y` at the illuminated
  region. Add a small `--beam-spread-mm` / divergence option (extends P0.3)
  once T0.6 numbers exist — a pencil beam vs a cm-scale spot changes
  pad-sharing comparisons.
- **Geometry deltas** from T0.1 (e.g. `--bulge-front 0 --bulge-back 0` if
  the chamber ran at ~atmospheric overpressure with negligible sag).
- **Physics**: standard EM + PAI in the gas region (P0.6). Keep muon
  radiative processes on — rare hard δ/brems events are in the data too and
  populate the charge-spectrum tail (§2.8).
- **Statistics**: 10⁵ general, 10⁶ for efficiency-vs-threshold points
  (the plateau inefficiency is a ≲1 % effect; need the zero/low-cluster
  tail populated).
- **Stage B**: Magboltz table for the as-run gas at the as-run drift field;
  gain/θ/transparency extracted at the as-run mesh voltage(s).
- **Stage C**: VMM emulator T1 tier with as-run peaking time, gain,
  threshold, neighbor-logic state, measured ENC (§2.1), and the as-run pad
  mapping. If NL was on, model it in **channel** space
  (`vmm.nl_map.PadMap.channel_neighbors`, with the as-run mapping revision) —
  not as geometric neighbors, which would give the wrong occupancy and the
  wrong cluster size.
- **Timing**: run `vmm/time_resolution.py` at the as-run gas, gap, peaking
  time and threshold *before* the data arrives, so the σ_t comparison stays
  blind-ish; then repeat through the full chain once Stage B exists. State
  whether the prediction is walk-corrected (we default to quoting both).
- Also simulate the **campaign reference gases** at the same 200 GeV μ
  point (campaign §4.3) so the tuned-vs-untuned shift can be quoted per gas.

## 4. Comparison — observable ↔ parameter matrix

Compare data (§2) to sim (§3) per observable; tune the **minimal parameter
set** {gain anchor (↔ Penning r), Polya θ, ε_mesh, ENC} globally — not
per-plot fudge factors. Document tuned values ± uncertainties in
`docs/testbeam/tb_tuned_params.json` (consumed by Stage B/C configs).

| observable | dominant model parameter(s) constrained |
|---|---|
| Landau MPV vs HV | **absolute gain scale + Penning r** — campaign risk §10.2, the big one |
| Landau width / resolution | Polya θ × primary-cluster statistics (PAI/Heed fidelity — the P0.6 validation gets a data point) |
| cluster size (pads) | transverse diffusion, pad sharing (NL state must match on both sides) |
| efficiency vs threshold | end-to-end chain; direct ε_e anchor |
| efficiency plateau vs HV | mesh transparency + gain model |
| pedestal/ENC | Stage C noise input (replaces estimate) |
| charge-spectrum tail | δ-ray + amp-gap direct-ionization modeling |
| drift-time span | Magboltz v_drift at operating field |
| **σ_t (walk-corrected)** | **primary-cluster density n_p × drift velocity v_d — σ_t ≈ (1.0–1.5)/(n_p·v_d); it constrains the *same* pair as the drift-time span, from the other end, so the two together over-determine v_d and test the ionization model** |
| **(PDO, TDO) walk curve** | **shaper model + threshold calibration; the shape is a stronger test than either projection** |

Method: χ²/pulls per observable at the tuned point; quote which
observables the tune *cannot* reconcile — those are model-shape failures,
not calibration, and route to §6.

## 5. Feedback into model + campaign

1. Freeze `tb_tuned_params.json`; make Stage B/C read it as the default
   parameter source.
2. **Re-run the campaign Phase-2 headline numbers** (ε_e at fixed γ
   rejection, threshold in fC) tuned vs untuned; the shift is the quoted
   modeling systematic — this is the concrete "feedback to our model".
3. Cross-check the tuned chain against the lab data we already have
   (`sr90_calibration/`, ⁵⁵Fe when taken): one parameter set must
   reproduce both beam and source data or the model is over-tuned.
4. Update `P2_MODEL.md` / campaign risk table: strike anchored items,
   keep what remains assumption (photon side, Ne transfer).

## 6. If it disagrees — escalation paths (don't tune past these)

Persistent shape disagreements map to known model simplifications; upgrade
in this order (all are campaign Phase-4 items, pulled forward on demand):

- cluster-size / residual shapes → measured mesh transparency curve or
  field-map, woven-mesh geometry instead of the effective slab;
- charge spectrum shape at low charge → Heed re-ionization (Stage B
  high-fidelity mode) instead of PAI clusters;
- efficiency-vs-threshold shape → full VMM waveform (Athena h(t)) with
  time-walk instead of T1 charge model;
- anything vs time/rate → pile-up / baseline effects, out of current scope,
  flag explicitly.

## 7. Sequencing

| step | depends on | status |
|---|---|---|
| T0 conditions + run manifest (§1) | **Alexandra** (logbook/run data) | **handed off 2026-08-05** — template at `testbeam/TB_CONDITIONS.md`; collectable while data analysis runs |
| data deliverables agreed + produced (§2) | analyzers (via Alexandra) | external; agree format early |
| P0.1 gas fix, P0.4/P0.4b/P0.6 output+physics, first lxplus build | us | campaign Phase 0, already planned |
| beam-spread gun option (§3) | T0.6 | small; extends P0.3 |
| muon sim runs (§3, campaign §4.3) | frozen geometry + T0 | after Alexandra's review |
| comparison + tune (§4) | both streams | |
| campaign re-derivation + systematics memo (§5) | tune | the deliverable |

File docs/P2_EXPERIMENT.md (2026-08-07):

# P2 @ MESA and the BASKET backward-angle program — research notes

**Compiled 2026-08-05** from public sources (deep web dive; every claim linked).
Status legend: ✅ well-sourced · ⚠️ inferred/computed (method shown) · ❌ not
public. Purpose: physics context and beam-condition inputs for this simulation.

---

## 1. P2 experiment basics

| Quantity | Value | Status | Source |
|---|---|---|---|
| Physics goal | sin²θW from PV asymmetry in elastic e-p; ⟨A⟩ = −39.94 ppb, ΔA = 0.56 ppb → Δsin²θW/sin²θW ≈ 0.13–0.15% | ✅ | [arXiv:1802.04759](https://arxiv.org/abs/1802.04759) (EPJA 54 (2018) 208) |
| Beam energy | **155 MeV** | ✅ | arXiv:1802.04759 |
| Beam current | 150 µA | ✅ | arXiv:1802.04759 |
| Polarization | 85% longitudinal, ΔP/P ≤ 0.5% | ✅ | arXiv:1802.04759; [arXiv:2402.01027](https://arxiv.org/html/2402.01027v1) |
| Target | Liquid H₂, **600 mm long**, r = 25 mm; L ≈ 2.4×10³⁹ cm⁻²s⁻¹ | ✅ | arXiv:1802.04759 §5.1.2 |
| Solenoid | Superconducting, **B_z ≈ 0.6 T**; FOPI field map used in design studies; real magnet delivered 11/2024 | ✅ | arXiv:1802.04759 §5; [P2 news](https://www.blogs.uni-mainz.de/fb08p2/) |
| Forward acceptance | θ = 25°–45°, 2π azimuth, ⟨Q²⟩ ≈ 6×10⁻³ (GeV/c)² | ✅ | arXiv:1802.04759 |
| Forward detector | 82 wedged fused-silica bars, r = 450–900 mm, integrating readout | ✅ | arXiv:1802.04759 §5.2 |
| Forward tracker | HV-MAPS, 4 layers / 2 double planes | ✅ | arXiv:1802.04759 §5.5 |
| Run time | 10,000 h; production from ~2026 | ✅ | arXiv:1802.04759; [Baunack HP2030 talk](https://indico.ijclab.in2p3.fr/event/10641/contributions/35364/attachments/24117/35046/Baunack_Hadron_Physics_2030.pdf) |

## 2. BASKET — the backward-angle program

**BASKET = "Backward Scattering Electron Tracker"** (IRFU/CEA-Saclay,
M. Boonekamp et al.). ✅

- **Physics:** PV asymmetry at backward angles → strange magnetic FF **G_M^s**
  and effective axial FF **G_A^{p,Z}**; reduces the hadronic-structure input
  uncertainty of the forward sin²θW extraction by ~4×. Options in the 2018
  paper: parallel running at 200 MeV (Q² = 0.1 GeV², A ≈ 7.5 ppm) or dedicated
  2×1000 h H/D runs at 150 MeV (Q² = 0.06 GeV²). ✅ arXiv:1802.04759 §7.3
- **Acceptance: θ = 140°–150°, full azimuth.** ✅ (same)
- **Configuration:** "three detection layers, each housing **7,680 pads**
  (~23,000 channels total)", trigger-less streaming, **15–20 kHz/pad**,
  ~**100 MHz** total backward-electron rate, design capability 100 GHz. ✅
  [MPGD 2026 abstract, Kallitsopoulou et al.](https://indico.cern.ch/event/1473492/contributions/7105990/);
  [P2 site](https://www.blogs.uni-mainz.de/fb08p2/the-p2-experiment/)
  - ⚠️ 6 wedges × 1,280 pads = 7,680 pads/layer, ×3 = 23,040 — **the
    3-wheels-of-6-wedges picture is arithmetically confirmed**; wheel
    z-positions and the r = 95–650 mm span are not public (internal design).
- **Technology:** low-material-budget **metallic (non-resistive) bulk
  Micromegas**; background rejection by 3-layer hit coincidence; **VMM3a**
  front-end (62 fC–2 pC range, sub-2.5 ns timing, expected signal ~21 fC,
  pad capacitance 75–170 pF); size-1 prototype tested at CERN SPS H4; first
  beam test at MAMI 06/2023. ✅ (MPGD 2026; P2 site; Baunack talk)
  - ⚠️ **"sub-2.5 ns timing" is the *front-end* figure, not the detector
    time resolution.** Our prediction for a pad *hit* is **σ_t ≈ 10–13 ns
    (argon mixtures) / 15–25 ns (neon mixtures)**, set by primary-ionization
    statistics as σ_t ≈ (1.0–1.5)/(n_p·v_d); the electronics terms (ENC
    jitter, TAC quantization) add < 3 ns in quadrature. The two numbers are
    not in conflict, but they must not be quoted interchangeably — and any
    coincidence-window or rate argument has to use the detector number.
    See `research/TIME_RESOLUTION_NOTES.md`.
- **Requirements** (ANR project BASKET-P2, ANR-23-CE31-0025): ±1° scattering
  angle, **2% momentum resolution**, 100 MHz readout, ~10¹⁴ events in ~1000 h.
  ✅ [ANR page](https://anr.fr/Projet-ANR-23-CE31-0025)
- Thesis to watch: M. Gailliard (U. Paris-Saclay, 2024–2027, Boonekamp/
  Vandenbroucke) [theses.fr/s405038](https://theses.fr/s405038); first BASKET
  publication expected as MPGD 2026 proceedings. ❌ no NIM/JINST paper yet.

## 3. Kinematics at the wedges (cross-check of "~100 MeV at ~10°")

Elastic recoil E′ = E/(1 + (E/M)(1−cosθ)) (⚠️ computed, endpoints reproduce
the paper's Q² values exactly):

| Beam | Target | θ=140° | 145° | 150° |
|---|---|---|---|---|
| 155 MeV | p | 120.0 | 119.2 | 118.5 MeV |
| 200 MeV | p | 145.3 | 144.1 | 143.1 MeV |
| 155 MeV | ¹²C | 151.3 | 151.2 | 151.1 MeV |

→ **"~100 MeV electrons" confirmed (119–145 MeV).**

**Incidence angle** (⚠️ computed): in a uniform 0.6 T solenoid the angle to
the beam axis is *conserved* at 180°−θ = **30°–40°**, with Larmor radius
R_L ≈ 380 mm and radial excursions up to 2R_L ≈ 630–920 mm (consistent with
the wedge span). A **~10° incidence requires fringe-field collimation**:
sin α = sin α₀·√(B/B₀) (adiabatic invariant), so α = 10° ⇒ **B at the wheels
≈ 45–70 mT** (B/B₀ ≈ 0.07–0.12), i.e. the wheels sit outside/behind the
solenoid bore — consistent with 2021 meeting notes preferring mounting
outside the vacuum chamber
([indico.in2p3.fr/event/23632](https://indico.in2p3.fr/event/23632/?note=2669)).
Caveats: adiabaticity is marginal (R_L ~ gradient scale), the angle has a
large spread with θ and vertex-z over the 60 cm target — **use the real field
map; confirm wheel z and local B with the collaboration.** ❌ not public.

## 4. Backgrounds & rates (Geant4 campaign inputs)

- Dominant backward background: **photons, 50–150 keV** signals; mitigated by
  layer coincidence + a photon shield (2024 CEA internship studied ~10 keV
  X-rays + shield). ✅ MPGD 2026; [internship PDF](https://irfu.cea.fr/Phocea/stages/pdf.php?id_stage=405)
- Rate budget: ~100 MHz real electrons vs 100 GHz capability → designed for
  ~10³ photon/electron ratio; 15–20 kHz/pad ⇒ occupancy ~10⁻³ per 100 ns (⚠️).
- Forward-region benchmarks for normalizing photon generators
  (✅ arXiv:1802.04759 Table 12): 1.54×10¹² hits/s on the quartz ring
  (1.14×10¹² bg photons vs 7.1×10¹⁰ signal e⁻); first tracker plane sees up to
  10⁶× more bremsstrahlung photons than signal; quartz dose ~80 Mrad/10kh.
  Backward-specific dose: ❌ not published.
- **Møller electrons** are kinematically forward (θ_lab < 90°) and cannot reach
  140°–150° directly (⚠️); low-energy Møllers spiraling along field lines +
  target bremsstrahlung are what to generate for backgrounds.

## Bottom line for this simulation

> **Working assumption adopted 2026-08-05 (Dylan):** the magnetic field
> exists around the target only; the backward wheels are **outside** it.
> So no B-field in this simulation — electrons arrive as straight tracks,
> centrally at ~10° from the wedge normal, and the campaign scans the
> incidence angle 0°–40° (and energy) to bracket the uncertainty.
> See `SIM_CAMPAIGN_BRIEF.md` §2.

- Primary particle: **electrons, ~119 MeV** (155 MeV beam baseline; 144 MeV
  for the 200 MeV option).
- **Incidence angle is the key open kinematic parameter**: ~10° if the wheels
  sit in the fringe field (B ≈ 50 mT) as believed, but 30–40° inside the bore.
  Plan the campaign to scan incidence 0°–40°; get wheel z-positions + field
  map to pin it down.
- Rates: 15–20 kHz/pad signal, photon background (50–150 keV) at ~10³× —
  a photon-response simulation of the wedge is a natural campaign component.
- Not public (ask Saclay): wheel z, gas mixture, drift/amp details (we have
  those confirmed internally: 3 mm / 150 µm), photon-shield design.

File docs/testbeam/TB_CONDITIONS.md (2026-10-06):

# SPS muon test beam — as-run conditions (FILL-IN)

**Status: TEMPLATE — every ⬜ NEEDED below is unanswered.**
**Owner of follow-up: Alexandra** (has the logbook and run data; Dylan
2026-08-05: "we'll leave this for Alexandra to follow up on").
Created 2026-08-05 by Dylan+Claude from `../TESTBEAM_PLAN.md` §1 (the
T0.x checklist); that doc explains *why* each item is needed and what the
answers feed. Replace each ⬜ NEEDED with the value + source (logbook page,
DAQ config file, elog link). Partial answers are useful — fill what you
know, mark the rest ⬜ UNKNOWN vs ⬜ NOT-YET-LOOKED-UP.

When complete: (1) strike the TEMPLATE line above, (2) fill
`tb_run_manifest.csv` (template in this directory, one row per run),
(3) ping the simulation side — every answer maps to a concrete sim setting
(right column), and sim replication runs are blocked on this file.

## Known so far (Alexandra, 2026-10-06)

| item | value | sim setting |
|---|---|---|
| Beam | **150 GeV muons**, perpendicular to the chambers | `-p muon -e 150000`, `--gun-theta 0` |
| Drift gap | **4 mm, same on every chamber** (frame V2; 3.964 mm of gas, `P2_MODEL.md`) | default |
| Pressure | "1 atm overpressure" as stated. Read as ~atmospheric absolute pressure with a few-mbar overpressure; ⬜ confirm the mbar value (it sets the window sag) | `--bulge-front/back` |
| Gases | **Ar/CO₂/iC₄H₁₀ 93/5/2** and **Ar/CF₄/iC₄H₁₀ 88/10/2** | `-g ArCO2Iso9352`, `-g ArCF4Iso` |
| Front-end settings | peaking time **200 ns** (mostly) and **100 ns**; gain **3.0** and **4.5 mV/fC** | `vmm/` emulator |
| Noise | use the **measured DREAM pedestal noise**; placeholder kept for a modelled noise if needed. VMM noise from the SNR code of the previous SPS campaign | Stage C |
| Run list | ⬜ to pick, see "Runs wanted" below | `tb_run_manifest.csv` |

### Runs wanted for the comparison

For **each gas**, at 200 ns / the gain mostly used:

1. **Mesh-HV scan at fixed drift field**: one run per point. Gives the gain
   curve (cluster-charge MPV vs HV), the anchor for Stage B's absolute gain.
2. **Drift-field scan at fixed mesh HV**, if taken: electron transparency
   and the drift-velocity/time-spread check.
3. **One high-statistics run at the working point**: cluster charge
   spectrum, cluster size (pads/cluster), efficiency, residuals and timing.
4. **The same working point at 100 ns and/or the other gain**: tests the
   front-end emulator separately from the detector physics.
5. **Pedestal/noise runs** taken alongside 1-3 (and the SNR-analysis output
   from the previous campaign) for the noise model.

Per run: run number, chamber(s) and which front-end (VMM or DREAM) each was
read with, mesh/drift HV, gas, peaking time, gain, threshold, and whether
neighbour logic was on.

---

## T0.1 Detector under test

| item | value | consumed by |
|---|---|---|
| Which detector? (P2 wedge / BASKET / other prototype; serial no.) | ⬜ NEEDED | whole geometry (Stage A) |
| Geometry deltas vs `docs/P2_MODEL.md` (drift gap, mesh, windows) | ⬜ NEEDED | `--drift-gap`, `--amp-gap`, … |
| Overpressure during the run (mbar) / visible window sag | ⬜ NEEDED | `--bulge-front/back` (0 if ~atmospheric) |
| Orientation: which face upstream; wedge rotation vs beam | ⬜ NEEDED | gun geometry |

## T0.2 Gas

| item | value | consumed by |
|---|---|---|
| Mixture + nominal fractions (vol %) | ⬜ NEEDED | `-g` flag + Magboltz table |
| Premix bottle or mixer? certificate / MFC settings | ⬜ NEEDED | fraction uncertainty on gain |
| Flow rate | ⬜ NEEDED | (context) |
| P/T logged? where? | ⬜ NEEDED | P/T gain correction (§2.7 of plan) |

## T0.3 High voltage — *the most valuable item*

| item | value | consumed by |
|---|---|---|
| Mesh (amplification) voltage(s) [V] | ⬜ NEEDED | Stage B gain point |
| Drift voltage(s) / field [V, V/cm] | ⬜ NEEDED | Magboltz drift point |
| **Was an HV scan taken? list the points** | ⬜ NEEDED | gain-vs-HV anchor — the single best dataset for calibrating the absolute gain scale (campaign risk §10.2) |
| Trips / unstable periods (runs to mask) | ⬜ NEEDED | comparison masks |

## T0.4 Readout / DAQ

| item | value | consumed by |
|---|---|---|
| Front-end: VMM3a hybrids? which DAQ (SRS?) | ⬜ NEEDED | Stage C emulator |
| Peaking time [ns] | ⬜ NEEDED | `vmm/` emulator setting |
| VMM gain [mV/fC] | ⬜ NEEDED | `vmm/` emulator setting |
| Threshold: DAC value and/or measured fC equivalent | ⬜ NEEDED | `vmm/` emulator setting |
| Neighbor logic on/off | ⬜ NEEDED | cluster-size comparison validity — NL-on and NL-off pad multiplicities are not comparable numbers |
| **Which pad-mapping revision** — `connector_*.txt` or `Mapping/connector_*.txt`? The two describe the same pad plane (to 2.5 µm) but assign channels to pads in almost entirely different orders (11/1280 agree) | ⬜ NEEDED | resolves campaign risk §10.6; decides what neighbor logic actually reads (a 12 mm neighbor vs a 126 mm one) and every per-channel comparison |
| DAQ config files archived? where? | ⬜ NEEDED | provenance |

## T0.4b Timing configuration *(added 2026-08-06 — needed for the σ_t comparison)*

We predict a per-pad time resolution of ~10–13 ns in argon mixtures and
15–25 ns in neon mixtures (`../research/TIME_RESOLUTION_NOTES.md`). None of
that can be compared with the data without these:

| item | value | consumed by |
|---|---|---|
| TDO mode: threshold-crossing time or time-at-peak? (per-chip setting) | ⬜ NEEDED | which quantity the emulator must reproduce — the two differ in walk behaviour and in model risk |
| TAC ramp used (60 / 100 / 350 / 650 ns) | ⬜ NEEDED | TDO quantization (LSB = ramp/2⁸); only the 650 ns ramp is non-negligible |
| BC clock frequency and TDO→ns conversion actually applied | ⬜ NEEDED | absolute time scale |
| Per-channel time offsets / TAC slope calibration: done? | ⬜ NEEDED | an uncalibrated channel spread inflates the pooled σ_t and looks like poor detector resolution |
| Time-walk correction applied in the analysis? functional form? | ⬜ NEEDED | we predict both raw and walk-corrected σ_t; a σ quoted without this label cannot be compared |
| Runs at more than one peaking time? | ⬜ NEEDED | σ_t vs t_p and the ballistic-deficit curve, both for free |

## T0.5 Trigger and reference tracking

| item | value | consumed by |
|---|---|---|
| Trigger: scintillators / telescope / self-triggered streaming | ⬜ NEEDED | which efficiency definition is possible |
| **What defines t = 0, and what is its time resolution?** (scintillator σ_t, telescope, or just the trigger BC — a 25 ns BC used as reference contributes 7.2 ns on its own) | ⬜ NEEDED | σ²_measured = σ²_pad + σ²_ref; without σ_ref the detector time resolution cannot be extracted at all |
| Reference tracker: type, resolution, geometry vs DUT | ⬜ NEEDED | efficiency + residual analyses |
| Other detectors in the stack (multiple wedges? order, spacing) | ⬜ NEEDED | layer-tag efficiency option |

## T0.6 Beam

| item | value | consumed by |
|---|---|---|
| μ⁺ or μ⁻; beamline (H2/H4/…) | ⬜ NEEDED | `-p muon` vs `muon+` |
| Momentum + spread (nominal 200 GeV) | ⬜ NEEDED | `-e` (MeV) |
| Spot size / divergence at the DUT | ⬜ NEEDED | beam-spread gun option (to be added) |
| Incidence angle(s) — normal only, or tilts too? | ⬜ NEEDED | if tilts: needs campaign P0.3 gun-angle work |
| Position(s) on the wedge illuminated / scanned | ⬜ NEEDED | `--gun-x/y` aim points |

## T0.7 Known pathologies

| item | value | consumed by |
|---|---|---|
| Dead / noisy channels list | ⬜ NEEDED | comparison masks |
| Saturation observed? | ⬜ NEEDED | ADC-saturation modeling |
| Other logbook anomalies worth masking | ⬜ NEEDED | run selection |

## T0.8 Data and analysis ownership

| item | value | consumed by |
|---|---|---|
| Raw-data location + format | ⬜ NEEDED | access |
| Who is analyzing what; timeline | ⬜ NEEDED | avoid duplication |
| Agreement on deliverable format (`../TESTBEAM_PLAN.md` §2: histograms + one summary CSV row per run/HV point) | ⬜ NEEDED | scriptable comparison |

---

## Run manifest

Fill `tb_run_manifest.csv` (template beside this file): one row per run —
`runID, date, HV_mesh_V, HV_drift_V, gas, threshold, angle_deg, pos_x_mm,
pos_y_mm, n_triggers, good(y/n), remarks`. Same no-un-manifested-runs rule
as the simulation campaign (`../SIM_CAMPAIGN_PLAN.md` §9).

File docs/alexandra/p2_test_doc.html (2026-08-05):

# P2 Micromegas — Simulation Campaign

Test document · Geant4 model of the P2 wedge · 2026-08-05

This is a formatting test — checking that this document reads well on your phone, offline. The real version will cover the full campaign plan. The content below is a small sample pulled from the repo.

## The detector at a glance

P2 wedge outline with active area and pad rings

The P2 wedge: 60° annular sector, board r = 95–650 mm, active area r = 120–590 mm.

Shape | 60° annular sector, apex on beam axis
Active area | r = 120 → 590 mm, ≈ 1689 cm²
Readout | 1280 pads = 10 × 128 ch; 42 rings, 11.43 mm pitch
Pillars | Ø0.5 mm, 2.000 mm pitch, 41 366 total
Readout PCB | 18 µm Cu / 200 µm FR4 / 18 µm Cu
Drift gap | 3 or 4 mm — unconfirmed

## The stack as modelled

Cross-section of the modelled material stack

Material stack in the Geant4 model, readout PCB to outer mylar window.

Things like this will be flagged for you: several dimensions in the model are educated guesses (drift gap, mylar thicknesses, bulge heights). The real doc will list each one with its source so you can check them.

If this renders well — figures sharp, table readable without zooming, comfortable text size — the full campaign doc will arrive in this format.

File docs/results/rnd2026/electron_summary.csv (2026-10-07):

gas | gap | theta | eff | mpv_keV | median_keV | cut99_keV | cut95_keV
ArIso | 3p964mm | 0.0 | 1.0 | 0.775 | 0.9874153068675728 | 9.735493143281268 | 3.373073828431621
ArIso | 3p964mm | 20.0 | 1.0 | 0.8250000000000001 | 1.0556617132246524 | 10.17267265358741 | 3.612479195491232
ArIso | 3p964mm | 40.0 | 1.0 | 1.225 | 1.3334214812939376 | 11.33176233328806 | 4.28671247399174
ArIso | 5mm | 0.0 | 1.0 | 1.125 | 1.2848276818812348 | 13.404126477915858 | 4.282703526405183
ArIso | 5mm | 20.0 | 1.0 | 1.0750000000000002 | 1.366088522321629 | 12.898287780111076 | 4.526087303325467
ArIso | 5mm | 40.0 | 1.0 | 1.625 | 1.722217204773683 | 15.030506084925566 | 5.289805021870655
ArIso9010 | 3p964mm | 0.0 | 1.0 | 0.925 | 1.0272724429539304 | 8.713668783596221 | 3.4081682550419847
ArIso9010 | 3p964mm | 20.0 | 1.0 | 0.875 | 1.0922348034826377 | 12.739900822257969 | 4.025662021923889
ArIso9010 | 3p964mm | 40.0 | 1.0 | 1.025 | 1.3589255892337826 | 12.971730954770663 | 4.3991916909833755
ArIso9010 | 5mm | 0.0 | 1.0 | 1.225 | 1.313197983282444 | 12.384838966228243 | 4.3705870303964565
ArIso9010 | 5mm | 20.0 | 1.0 | 1.225 | 1.411268156483933 | 11.928192564550889 | 4.675711488621864
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

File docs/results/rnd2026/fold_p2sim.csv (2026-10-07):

layer | gas | gap | flux_10_150keV_MHz | flux_total_MHz | detected_MHz | detected_after_cut99_MHz
MM0 | ArIso | 3p964mm | 39724 | 47120 | 79.10 | 41.49
MM0 | ArIso | 5mm | 39724 | 47120 | 88.79 | 62.23
MM0 | ArIso9010 | 3p964mm | 39724 | 47120 | 76.40 | 37.69
MM0 | ArIso9010 | 5mm | 39724 | 47120 | 88.53 | 59.91
MM0 | NeIso | 3p964mm | 39724 | 47120 | 37.15 | 19.60
MM0 | NeIso | 5mm | 39724 | 47120 | 39.00 | 23.80
MM0 | NeIso8515 | 3p964mm | 39724 | 47120 | 37.12 | 20.20
MM0 | NeIso8515 | 5mm | 39724 | 47120 | 37.74 | 21.52
MM1 | ArIso | 3p964mm | 32047 | 38928 | 30.41 | 17.79
MM1 | ArIso | 5mm | 32047 | 38928 | 31.28 | 20.04
MM1 | ArIso9010 | 3p964mm | 32047 | 38928 | 29.23 | 15.65
MM1 | ArIso9010 | 5mm | 32047 | 38928 | 32.71 | 19.87
MM1 | NeIso | 3p964mm | 32047 | 38928 | 21.83 | 12.35
MM1 | NeIso | 5mm | 32047 | 38928 | 22.32 | 13.39
MM1 | NeIso8515 | 3p964mm | 32047 | 38928 | 21.84 | 11.82
MM1 | NeIso8515 | 5mm | 32047 | 38928 | 21.70 | 11.76
MM2 | ArIso | 3p964mm | 26551 | 32824 | 24.65 | 14.46
MM2 | ArIso | 5mm | 26551 | 32824 | 25.30 | 16.17
MM2 | ArIso9010 | 3p964mm | 26551 | 32824 | 23.70 | 12.71
MM2 | ArIso9010 | 5mm | 26551 | 32824 | 26.51 | 16.05
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

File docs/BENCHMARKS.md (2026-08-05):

# Measured speed and campaign cost

**Written:** 2026-08-05, on `lxplus925` (16 cores, AlmaLinux 9, Geant4
11.2.p01 + LCG_106 ROOT from CVMFS). This is the **first time the P2
simulation has run at all**, so these are also the first numbers on whether
the campaign is affordable. Short answer: **it is, comfortably — compute is
not the binding constraint on this campaign.**

Reproduce with **`bash scripts/benchmark_lxplus.sh`** (or `quick` for just
the cost-model fit).

> **Methodology note.** lxplus login nodes are shared and were running at
> load 9–15 throughout, so **wall-clock timings there are meaningless.** All
> per-event costs below are **user CPU time** (`/usr/bin/time %U`), which is
> only mildly affected by contention. An early run of this benchmark was
> discarded because two instances were accidentally running at once.

---

## 1. The cost model

Every job pays a **fixed startup cost** (geometry construction, physics
table building) plus a marginal per-event cost. Fitted from event-count
scans at 119 MeV e⁻ (200 / 1 000 / 5 000 / 20 000) and 60 keV γ
(5 000 / 50 000), single-threaded:

| | startup | marginal | throughput |
|---|---|---|---|
| **γ, 60 keV** | 6.6 s | 0.50 ms/event | **≈ 2 000 γ/s/core** |
| **e⁻, 119 MeV** | 6.4 s | 1.82 ms/event | **≈ 550 e⁻/s/core** |

The fit predicts 56.5 s of CPU for 10⁵ γ (measured 56.0) and 10.0 s for
2 000 e⁻ (measured 10.4), so it is good to a few percent.

**Independently reproduced** by a second, later run of
`scripts/benchmark_lxplus.sh quick` on the same node at a different load:
0.502 ms/γ (1 990 γ/s) and 1.77 ms/e⁻ (565 e⁻/s), startup 6.5–6.9 s. That
pass added a third photon point (2×10⁵) which confirms strict linearity —
predicted 107.3 s CPU, measured 107.26 s. Take the spread between the two
passes (≈3 %) as the reproducibility on a shared node.

**The 6.5 s startup is the reason not to submit tiny Condor jobs.** At
10⁴ events a photon job is ~57 % startup overhead; at 10⁶ it is 1 %. Size
jobs at ≥10⁶ photons or ≥10⁵ electrons.

## 2. Raw measurements (single thread unless noted)

| run | N | CPU user [s] | rate [ev/s] | output | written |
|---|---|---|---|---|---|
| γ 8 keV, ArIso, skip-empty | 10⁵ | 45.6 | 2190 | 7.93 MB | 5551 |
| γ 60 keV, ArIso, skip-empty | 10⁵ | 56.0 | 1790 | 575 kB | 347 |
| γ 100 keV, ArIso, skip-empty | 10⁵ | 54.6 | 1830 | 322 kB | 172 |
| γ 150 keV, ArIso, skip-empty | 10⁵ | 54.9 | 1820 | 224 kB | 109 |
| γ 60 keV, **NeIso**, skip-empty | 10⁵ | 56.7 | 1770 | 426 kB | **301** |
| γ 60 keV, ArIso, **no** skip-empty | 10⁵ | 57.2 | 1750 | **1.89 MB** | 100000 |
| e⁻ 30 MeV, ArIso | 2000 | 11.4 | — | 2.17 MB | 2000 |
| e⁻ 119 MeV, ArIso | 2000 | 10.4 | — | 2.01 MB | 2000 |
| e⁻ 155 MeV, ArIso | 2000 | 10.0 | — | 2.00 MB | 2000 |
| e⁻ 119 MeV, NeIso | 2000 | 9.7 | — | 1.73 MB | 2000 |
| μ 200 GeV, ArIso | 2000 | 8.8 | — | 1.72 MB | 2000 |
| γ 60 keV, 8 threads | 4×10⁵ | 208.5 | 11 019 (wall) | 2.52 MB | 1384 |
| e⁻ 119 MeV, 8 threads | 8000 | 21.4 | — | 8.01 MB | 8000 |

(The short 2000-event runs are startup-dominated — do not read a throughput
off them; use §1.)

Observations worth carrying:

- **Photon cost is nearly independent of energy** across 8–150 keV. It is
  dominated by geometry navigation of the un-interacting photon, not by
  physics. So the expensive photon points are the ones with high statistics,
  not the ones at high energy.
- **8 keV is the cheapest but bulkiest** — 5.5 % of photons interact, giving
  14× the output of the 60 keV run.
- **Gas choice barely changes runtime** (Ne vs Ar within 2 %).
- **200 GeV muons are the cheapest particle we run.** The test-beam
  validation points (plan §4.3) are free.

## 3. Multithreading

8 threads on 400 k photons: 36.3 s wall against an extrapolated 243 s
single-threaded → **6.7× speedup, 84 % efficiency**, and total CPU is the
same as the single-thread run per event (no MT overhead). On a shared login
node at load ~12 that is a floor, not a ceiling.

For HTCondor the useful mode is still **1 thread per job, many jobs** —
scaling is embarrassingly parallel across run points and avoids the shared
ROOT-file merge. MT is for interactive work.

> Multithreading only works as of 2026-08-05: every `-t > 1` run used to
> core-dump in `TTree` construction because ROOT's global class registry is
> not thread-safe. Fixed with `ROOT::EnableThreadSafety()` in `mm_sim.cc`.
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

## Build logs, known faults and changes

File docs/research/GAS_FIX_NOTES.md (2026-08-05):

# The gas-mixture fix (P0.1) — two bugs, and what they invalidated

**Written:** 2026-08-05. Status: **fixed, verified in Geant4, and the
affected results re-measured.** Code: `DetectorConstruction.cc`
(`idealRho` + `makeMixV`). Campaign context: `../SIM_CAMPAIGN_PLAN.md` §3
task P0.1.

Every simulated gas in this repo was wrong in two independent ways until
2026-08-05. Both are now fixed by construction rather than by correcting
the numbers, so neither can silently come back.

---

## 1. Bug A — volume fractions passed as mass fractions

`G4Material::AddMaterial(mat, fraction)` takes a **mass** fraction. The
builder handed it the **volume** fraction, which is how gas mixtures are
specified everywhere else (gas systems, literature, our own plan).

For ideal gases at a common temperature and pressure the conversion is

```
    f_mass,i = f_vol,i · ρ_i / Σ_j (f_vol,j · ρ_j)
```

so the error scales with how much the component densities differ from the
carrier's. Isobutane is 2.9× denser than argon and 5.8× denser than neon:

| mixture | intended (volume) | what was simulated (mass) |
|---|---|---|
| Ar/Iso 95/5 | 95 / 5 | **92.9 / 7.1** |
| Ne/Iso 95/5 | 95 / 5 | **86.8 / 13.2** |
| Ar/CO₂ 70/30 | 70 / 30 | 67.9 / 32.1 |
| He/Ethane 96.5/3.5 | 96.5 / 3.5 | 78.5 / 21.5 |

The neon case is the serious one: **2.6× the intended isobutane content by
mass.** Since the whole campaign exists to compare argon against neon, and
the error is 2.4 % in argon but 13 % in neon, it biased exactly the
comparison the campaign is for. He/Ethane is worse still (6× the intended
ethane) but that mixture is inherited MX17 and not on the campaign list.

## 2. Bug B — densities were STP values in a 20 °C material

Independently, every component density was hard-coded at the **0 °C** value
while the `G4Material` declared 293.15 K:

| gas | hard-coded | ideal gas at 20 °C | ratio |
|---|---|---|---|
| Ar | 1.7820 | 1.6607 | 1.073 |
| Ne | 0.8999 | 0.8389 | 1.073 |
| He | 0.1786 | 0.1664 | 1.073 |
| CO₂ | 1.9770 | 1.8295 | 1.081 |
| CF₄ | 3.7200 | 3.6584 | 1.017 |
| iC₄H₁₀ | 2.6700 | 2.4162 | 1.105 |
| C₂H₆ | 1.3560 | 1.2500 | 1.085 |

(mg/cm³.) The uniform 1.073 factor is exactly 293.15/273.15 — these are
textbook STP densities. **Every gas was ~7 % too dense**, which propagates
directly into dE/dx, primary-ionization counts, and photon interaction
probability. It also explains a discrepancy noticed earlier: the analytic
budget in `PHOTON_DISCRIMINATION_NOTES.md` used 20 °C densities and so
disagreed with the simulation's gas conversion rate by ~7 % for reasons
that had nothing to do with physics.

The isobutane value (2.67) is not even the 0 °C ideal figure (2.593); it
looks like a real-gas density at ~0 °C. The plan's P0.1 already flagged it
as suspicious.

Combined, the mixture densities were off by **−7.0 % (Ar/Iso)** and
**−10.3 % (Ne/Iso)** — neon worse because both bugs pushed the same way.

## 3. The fix

Both are now derived rather than tabulated:

- `idealRho(molarMass)` computes each pure-gas density from the molar mass
  at the declared 20 °C / 1 atm. Changing the operating temperature or
  pressure now changes the densities consistently, and there is no second
  place for a stale number to hide.
- `makeMixV(name, {{mat, volumeFraction}, ...})` takes **volume** fractions,
  derives the mixture density as Σ fᵢρᵢ and the mass fractions as
  fᵢρᵢ/ρ_mix, and throws if the volume fractions do not sum to 1. The
  density is no longer computed separately at each call site (which was the
  structural reason the two numbers could disagree in the first place).

Ideal gas is good to <1 % for the noble gases, CO₂ and CF₄ at 1 atm. The
worst real-gas deviation is isobutane, ~2 % denser than ideal at 20 °C; at
≤20 % quencher that is <0.4 % on any mixture here, well inside the P/T
control of a real gas system. Documented in the code rather than corrected
with an invented compressibility factor.

**Verified in Geant4**, not just on paper — `printMaterial` reports:

```
Material: ArIso  density: 1.698 mg/cm3   ElmMassFraction: Ar 92.89 %
          ElmAbundance: Ar 57.58 %, C 12.12 %, H 30.30 %
Material: NeIso  density: 0.918 mg/cm3   ElmMassFraction: Ne 86.84 %
          ElmAbundance: Ne 57.58 %, C 12.12 %, H 30.30 %
```

The atom fractions are the check that matters: 95 Ar + 5 C₄H₁₀ per 100
volumes is 95 : 20 : 50 atoms = 57.6 : 12.1 : 30.3 %. Exact.

## 4. What this invalidated

Everything simulated before 2026-08-05 night, which is one day's worth of
first runs. Specifically:

- The **first photon run numbers** in `PHOTON_DISCRIMINATION_NOTES.md`
  §4.3a were taken with argon 7 % too dense and neon 10 % too dense, and
  with neon carrying 2.6× the intended isobutane.
- The **Ar-vs-Ne comparison** (347 vs 301 events per 10⁵ γ) was the result
  most at risk, since the two gases were wrong by different amounts (−7 %
  vs −10 % in density, 2.4 % vs 13 % in composition). In the event it
  barely moved — 13 % → (12 ± 3) % — because the gas-dependent part of the
  rate is only ~10 % of the total to begin with.
- The **benchmarks** in `BENCHMARKS.md` are unaffected in any way that
  matters: runtime is dominated by geometry navigation, and a 7 % density
  change moves the interaction rate, not the cost per event.

**Corrected numbers are in `PHOTON_DISCRIMINATION_NOTES.md` §4.3a**
(re-measured at 4×10⁵ γ per gas, 4× the original statistics). What moved:

| quantity | pre-fix | post-fix |
|---|---|---|
| photon-induced hit rate, Ar/Iso | 3.47×10⁻³ | 3.53×10⁻³ |
| photon-induced hit rate, Ne/Iso | 3.01×10⁻³ | 3.11×10⁻³ |
| Ar → Ne reduction | 13 % | **(12 ± 3) %** |
| Micromesh conversion rate | 1.98×10⁻³ | 2.10×10⁻³ |
| DriftGas conversion rate (Ar) | 3.05×10⁻⁴ | 3.10×10⁻⁴ |

Almost nothing, and for a reason worth stating: **the dominant fake source
is the walls, whose conversion rate does not depend on the gas at all.** The
mesh and pad-copper rates should have been identical before and after, and
they are, within counting statistics. Only the small direct-gas component
moved, and the two bugs partly cancelled in it (denser gas ⇒ more
conversions; the density error was the larger effect and pushed both gases
the same way).

The qualitative conclusion — walls dominate, argon and neon are close — was
never at risk from this. But the *number* people will quote (the Ar-vs-Ne
gap) was, and it is now measured on a correctly-constituted gas.

## 5. Still open

- **The campaign gas list is not implemented** (plan P0.2). Only the
  inherited eight mixtures exist; the §7.4 candidates (Ne/CO₂ 90/10 = N10,
  Ne/Iso 90/10, the ternaries) still need adding. With `makeMixV` this is
  now a one-line entry each, specified the way the plan quotes them.
- **W values are still per-mixture constants** in `SteppingAction`, not
  derived from composition, and they do not account for Penning transfer.
  That is a separate bias on Ar-vs-Ne comparisons made on `nPrimary` rather
  than `edep` — see `PHOTON_DISCRIMINATION_NOTES.md` §5.2 and plan §5
  step 3a.
- Pressure is assumed 1 atm everywhere. If the chamber runs at slight
  overpressure (the windows bulge, so it does), the densities scale
  linearly and `idealRho` is where to apply it.

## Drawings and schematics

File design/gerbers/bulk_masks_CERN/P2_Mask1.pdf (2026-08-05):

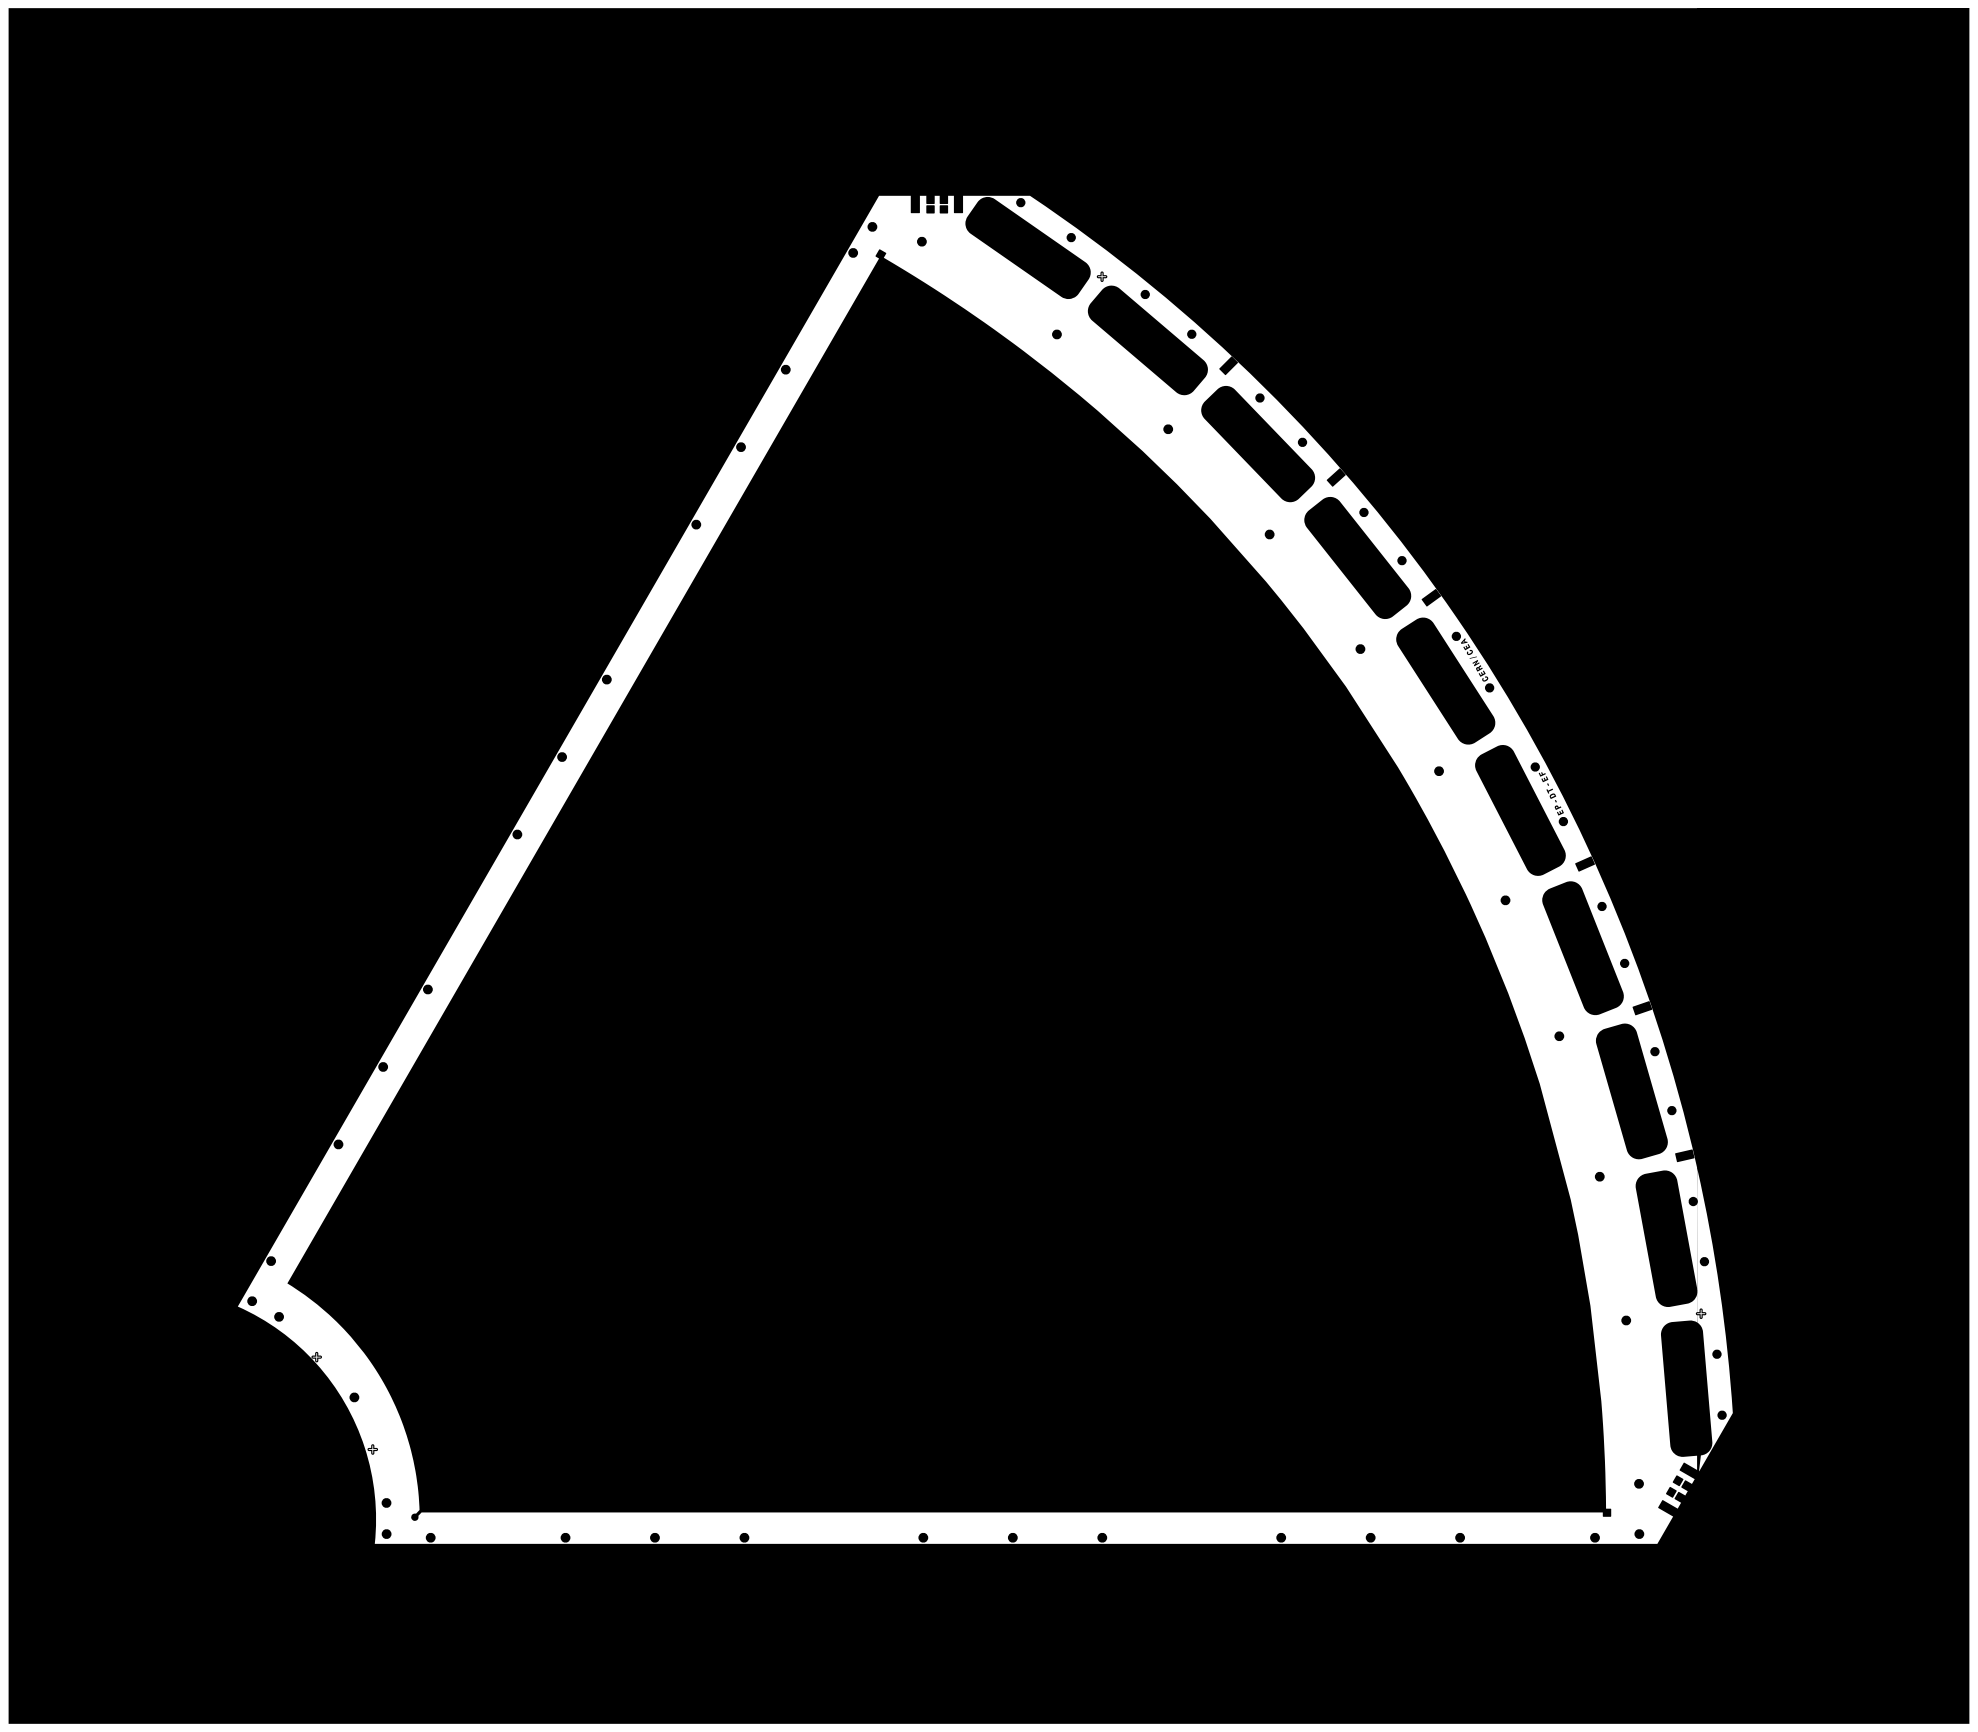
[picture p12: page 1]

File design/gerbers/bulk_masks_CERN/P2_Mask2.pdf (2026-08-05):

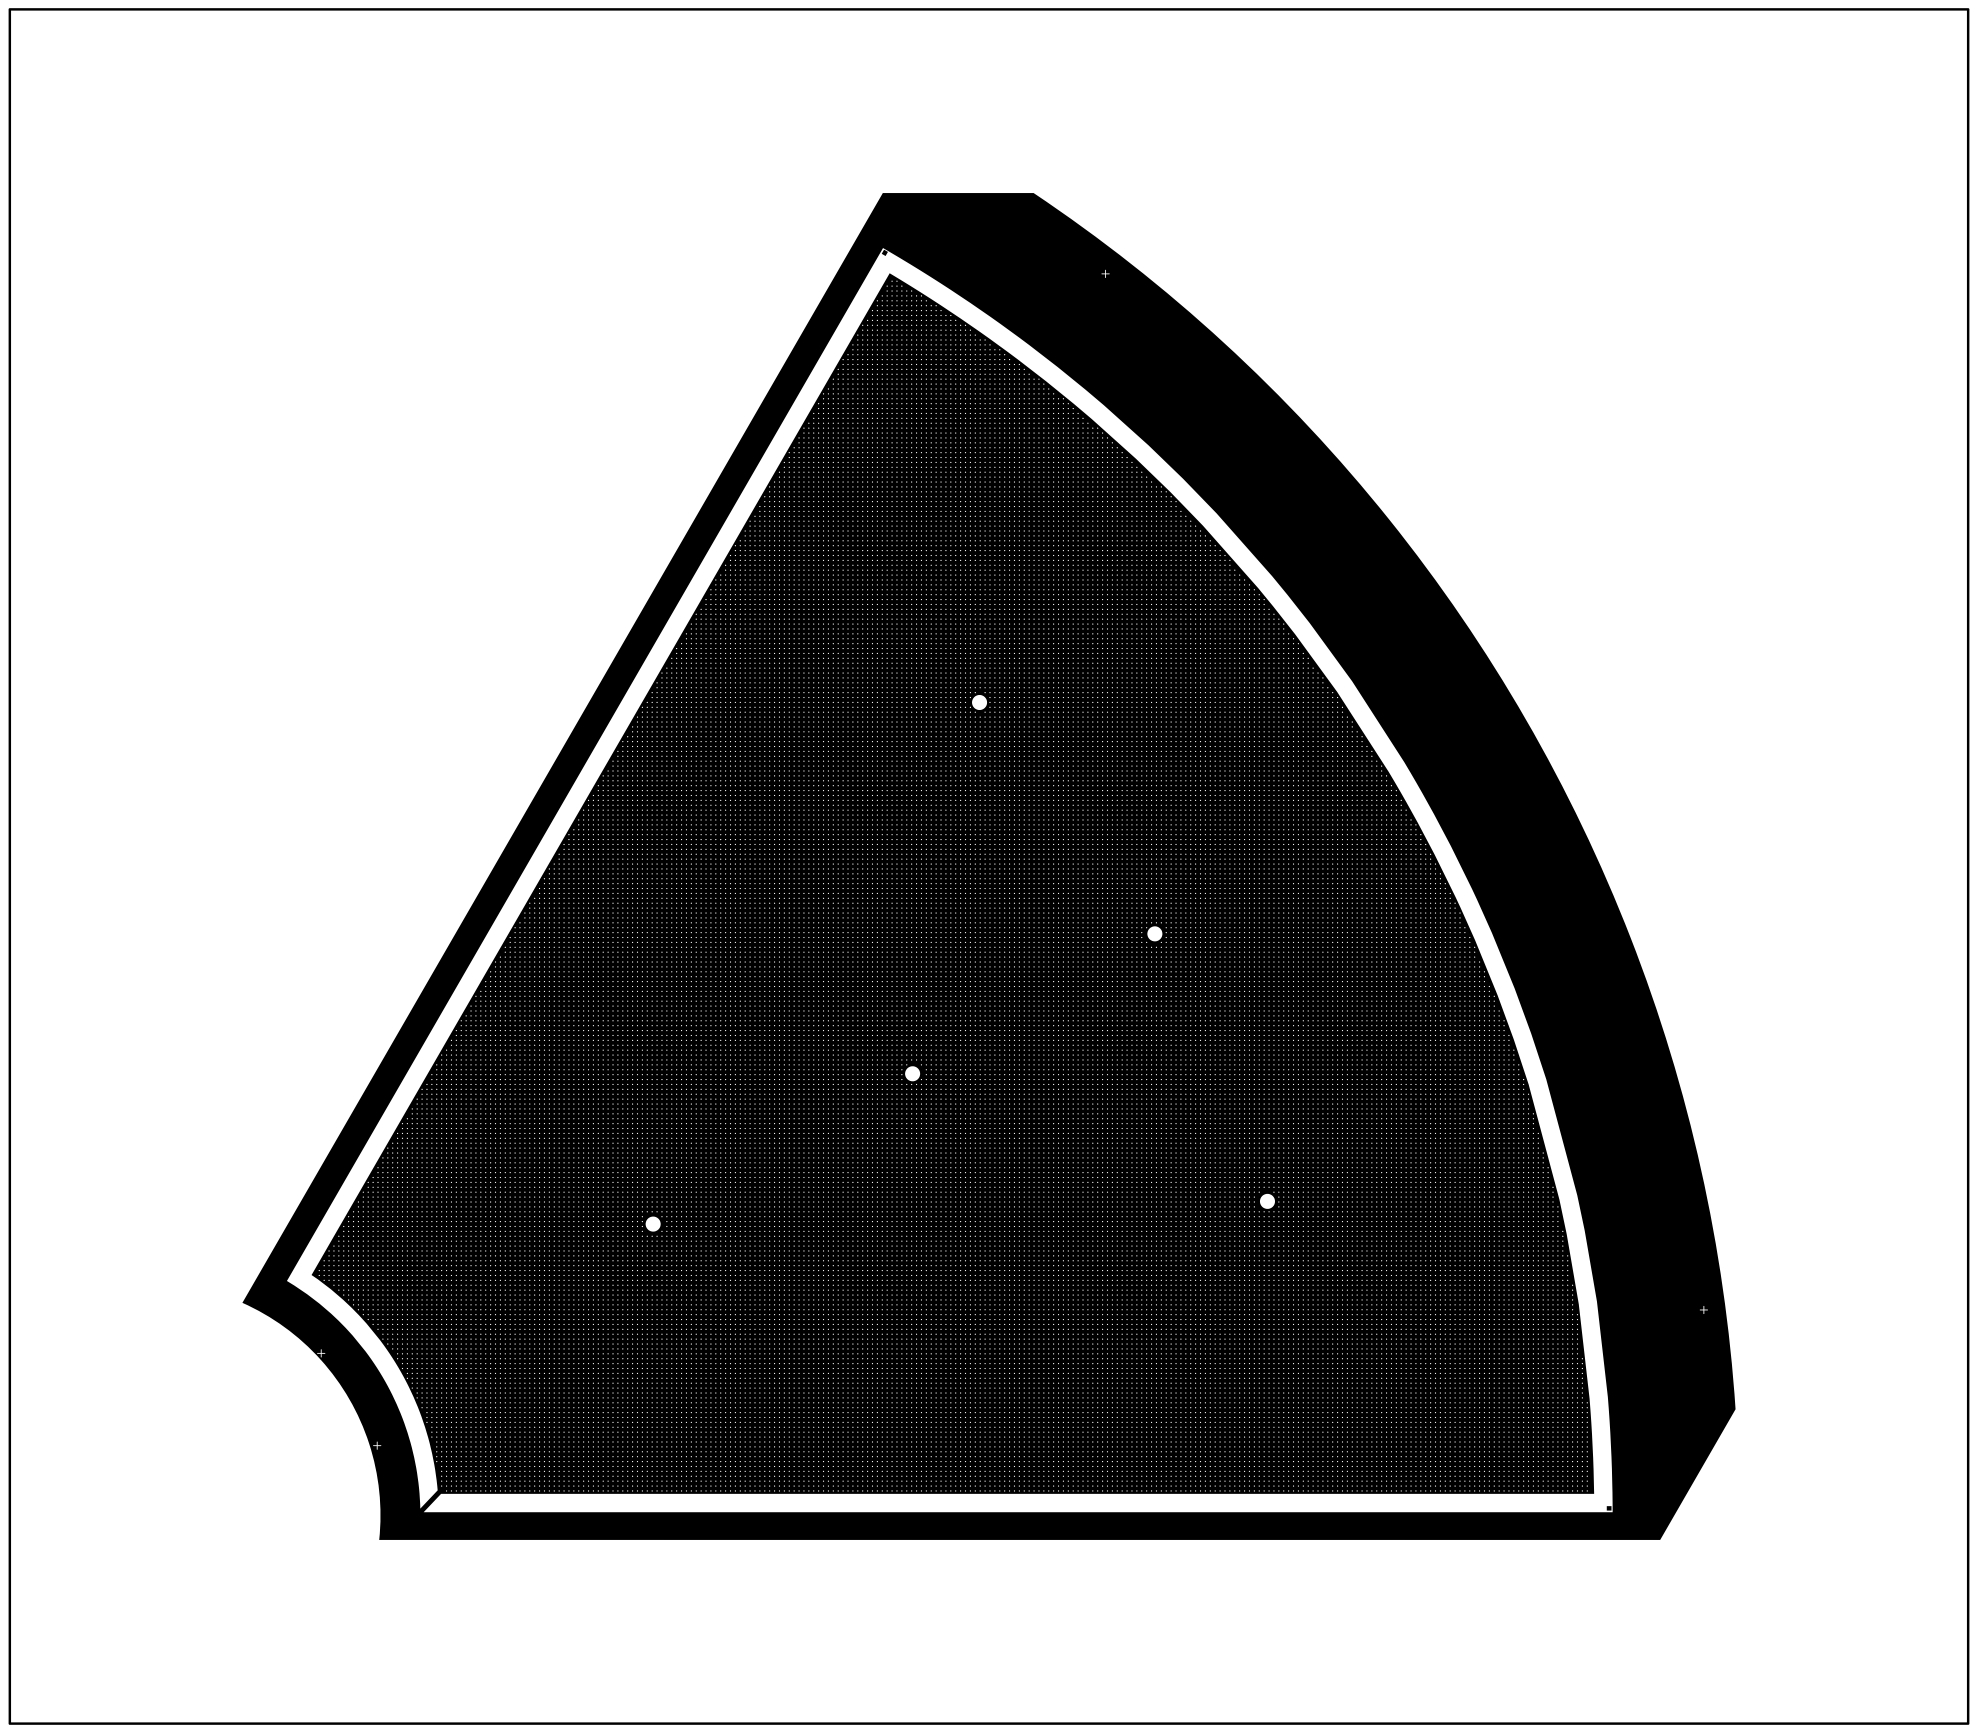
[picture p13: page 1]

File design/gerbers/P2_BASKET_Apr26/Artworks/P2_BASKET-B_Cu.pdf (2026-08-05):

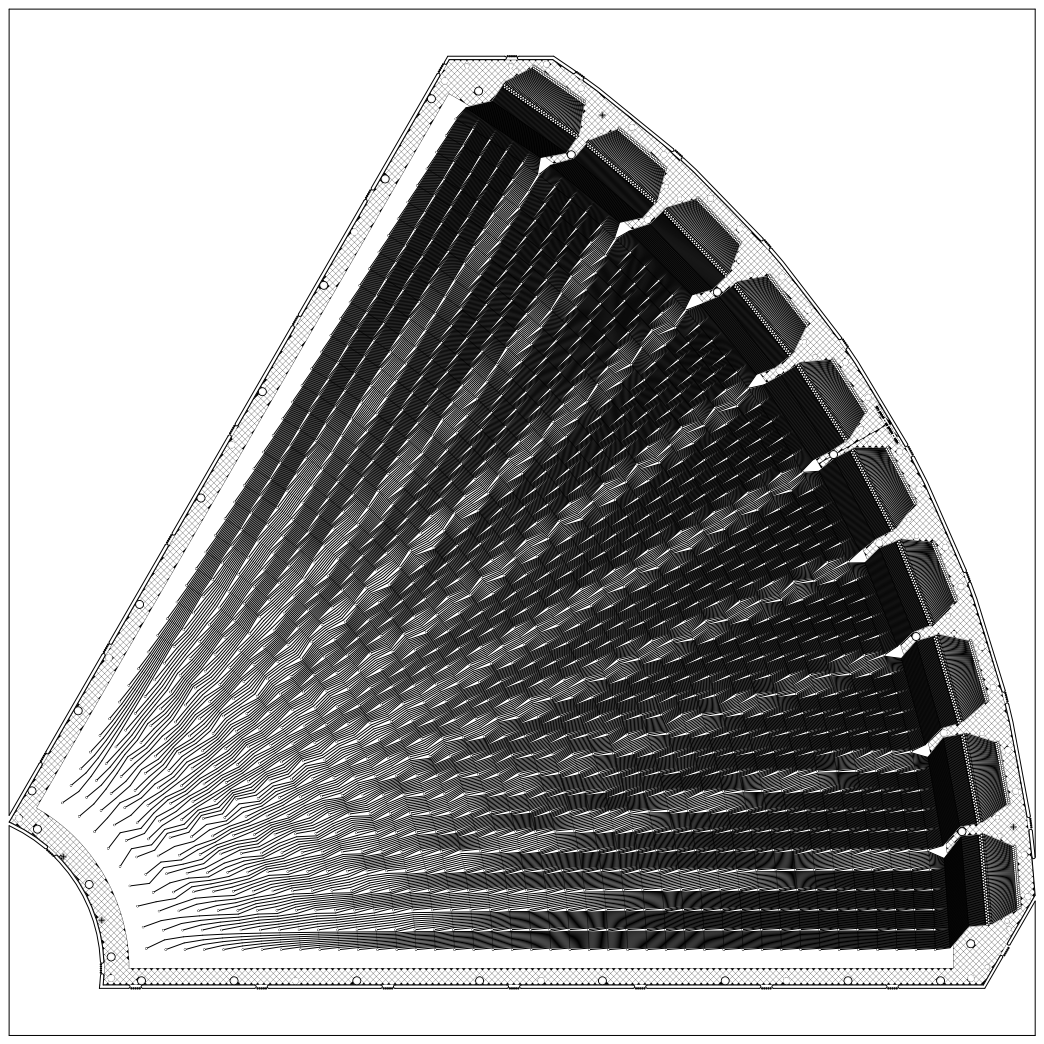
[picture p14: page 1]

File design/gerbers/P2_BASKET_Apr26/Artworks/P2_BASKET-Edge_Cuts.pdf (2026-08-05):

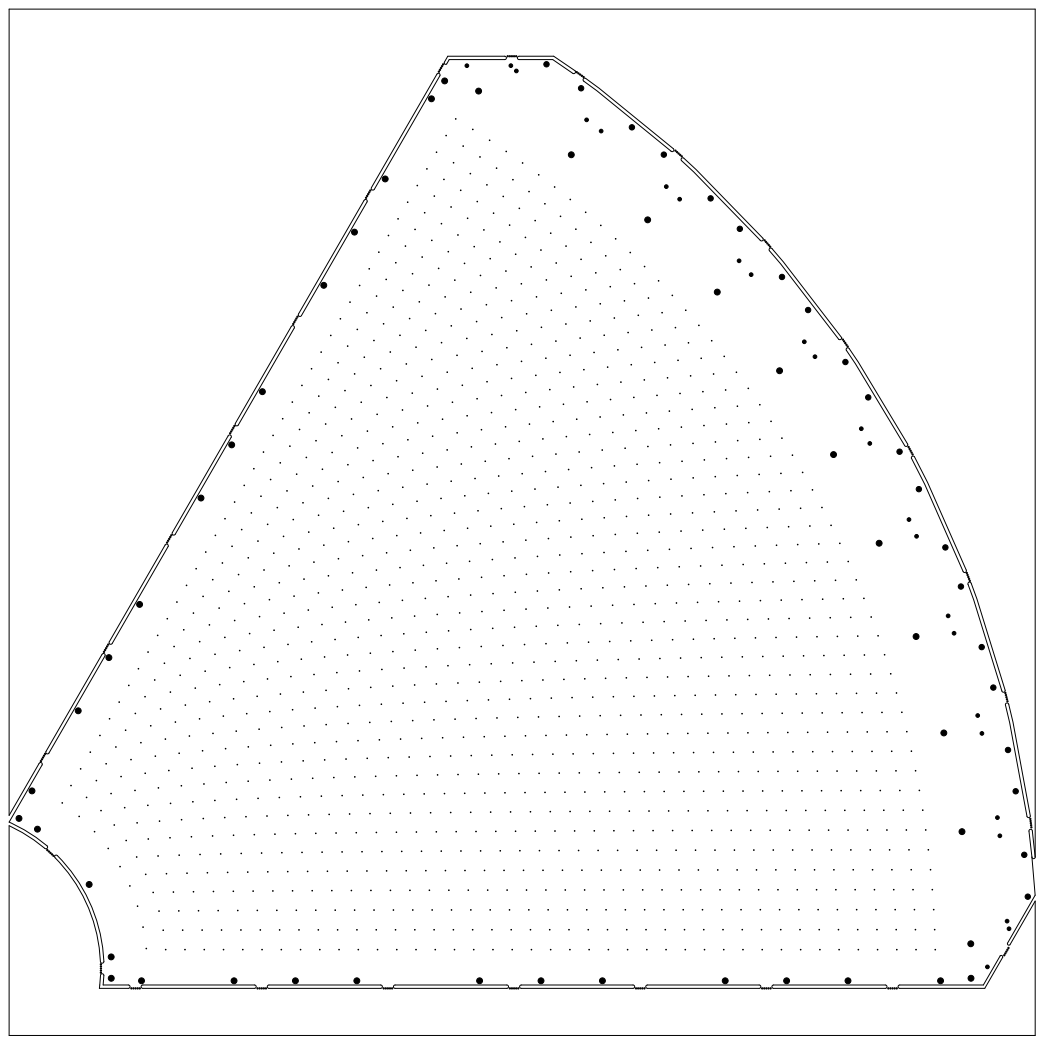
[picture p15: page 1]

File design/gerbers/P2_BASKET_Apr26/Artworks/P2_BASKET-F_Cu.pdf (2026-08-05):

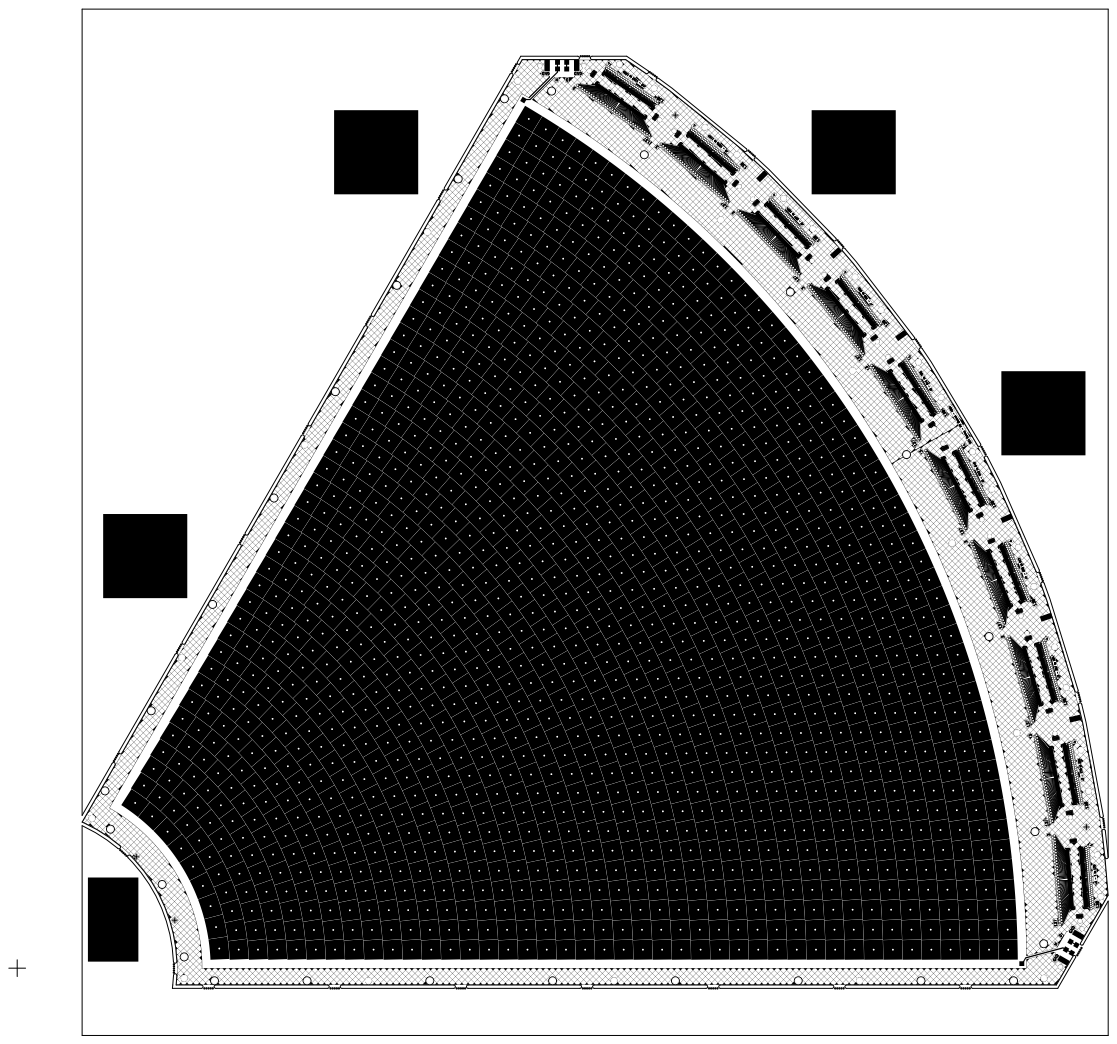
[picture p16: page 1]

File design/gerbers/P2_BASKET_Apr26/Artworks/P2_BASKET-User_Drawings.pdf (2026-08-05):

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

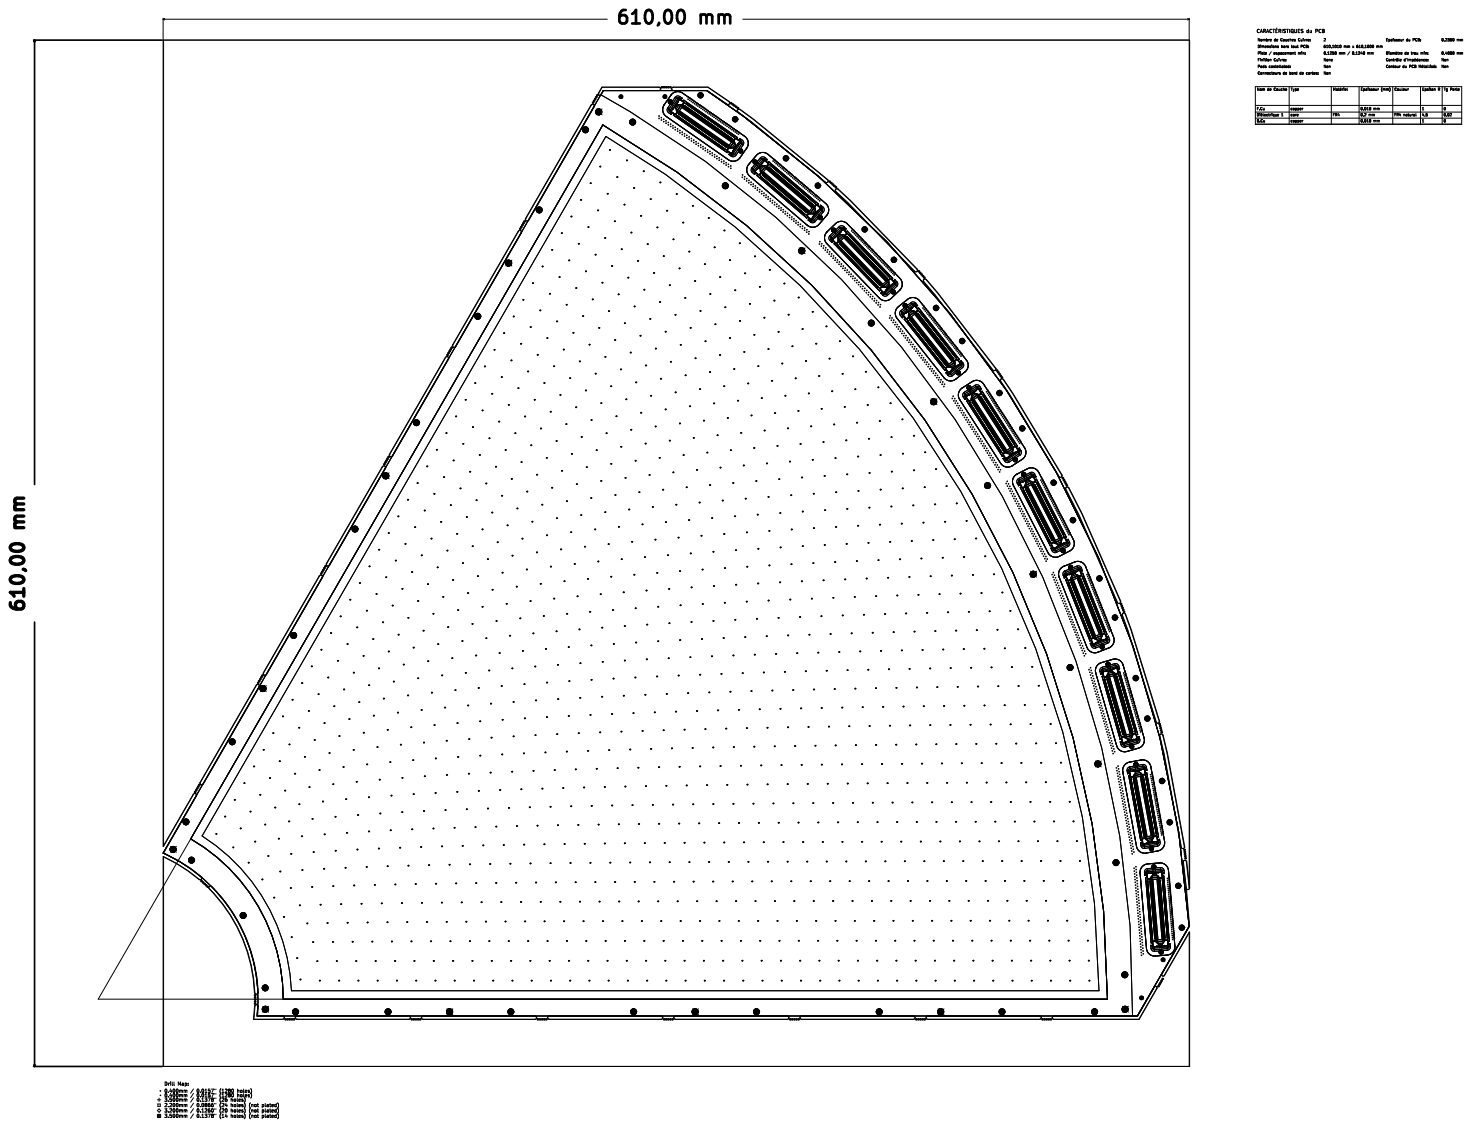
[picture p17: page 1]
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

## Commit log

2026-08-05 Initial import: P2 wedge Micromegas Geant4 simulation
    The repository so far has no history — this commits the whole working tree
    as it stands, then the session's work is described below.
    Contents
    --------
    - Geant4 application (`mm_sim.cc`, `src/`, `include/`): the P2 wedge as the
    default `p2` mode, plus the inherited MX17 modes. Full stack in gerber
    coordinates: bulged mylar windows, gas frame, two-foil drift cathode,
    drift gap, woven mesh as an effective-density slab, amplification gap,
    readout PCB, carbon back frame.
    - `design/`: P2 fabrication data (gerbers, drill, bulk masks, channel
    mapping, mechanical STEP) — the source of every measured dimension.
    - `scripts/gerber/`, `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
    [BOM_Fx2Mec8.csv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]
2026-08-06 Note bulk pillars as an unmodelled item (MX17 measured 0.6/4.68 mm grid)
2026-08-07 Note three readout-accuracy upgrades from MX17 that apply to P2
    Landed in MX17_Geant this week; recording what they would mean here so the
    next person on the P2 geometry does not have to rediscover them. Ordered by
    effort/benefit, with the needed input stated for each.
    1. Zone the Cu coverage. SimConfig documents p2_fcu_coverage = 0.983 /
    p2_bcu_coverage = 0.174 as measured over the ACTIVE AREA, but EffCu then
    applies them to a slab spanning the whole wedge board, so the model puts
    near-solid copper out in the fan-out. MX17 had the mirror image of this
    (one board-wide average everywhere: 26 % too little copper in the active
    area, ~10x too much outside). Fix is two volumes and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
2026-08-07 Re-scope the VMM analysis for a pad detector, not a strip detector
    Work from 2026-08-06, uncommitted until now.
    The charge cloud fires ~1.1 pads on average, so inter-pad clustering is a
    ~10 % minority effect rather than the several-channel cluster that ATLAS
    NSW's neighbor logic, uTPC and cluster-size cuts were designed around.
    Anything inherited from NSW has to be re-derived, not transplanted.
    The concrete finding is that VMM neighbor logic fires on *chip-channel*
    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
2026-08-07 Add the time-resolution toy MC (2026-08-06 work)
    Standalone predictor for the per-pad time resolution, no Geant4 and no
    Stage B, about a minute per configuration. Exists because timing became a
    Stage C deliverable rather than a Phase-4 option: we want to compare the
    VMM's measured time resolution at SPS against a prediction.
    Chain per event: Poisson clusters along the track -> electrons per cluster
    from p(n) ~ n^-2 -> drift with Gaussian longitudinal diffusion -> Polya
    gain -> Athena closed-form VMM shaper -> interpolated threshold crossing ->
    analytic ENC jitter -> TAC quantization -> optional walk correction on PDO.
    Headline result is that sigma_t is not an electronics number: it is
    ioni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
2026-08-07 Integrate the outstanding MX17 suggestions and ticket the readout upgrades
    HANDOFF_MX17_RESPONSE.md collected suggestions flowing back from the MX17
    response-simulation effort. Only the pillar-material item had been acted
    on; five others were written down and never reached the plan. Working
    through them:
    2.1 induction upgrade -> promoted out of Phase 4 to P0.17. The original
    cost estimate was wrong for our stack: MX17 needs a semi-spectral
    quasi-static solver because it is resistive, P2 is not, so the
    weighting potential is static and closed-form (Riegler, JINST 11
    (2016) P11002, already in Garfield++ ComponentParallelPlate). An
    afternoon, not a phase -- and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
2026-08-07 Move the default beam off a pad boundary, add --beam-spread, record MX17 traps
    Readiness review ahead of handing the repo to Alexandra, plus a pass over
    the MX17_Geant repo for lessons. Three findings, one of them a live bug.
    1. The default gun aim point sat on a pad boundary.
    (307.4, 177.5) was picked as a round "r = 355 mm, phi = 30 deg" for the
    middle of the active area. Pad ring centres are at 120.714 + n*11.4290 mm,
    so 349.286 and 360.715 straddle it: the default beam landed 35 um from a
    radial pad boundary, i.e. 49.7 % of a ring pitch from the nearest pad
    centre.
    A pencil beam parked on a boundary makes "which pad has the most charge" a
    coin flip and inflates pad multiplicity, and i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
2026-08-07 Model the readout copper from the real artwork, not one board-wide average (P0.19)
    Authored by a parallel Claude Code session working in this checkout; cleared
    by Dylan on the strength of a written summary of the diff rather than a
    line-by-line read.
    The F.Cu pad field is now real geometry: 1280 annular-sector pads on the
    gerber-exact polar grid, built as 42 G4PVReplica rings, costing 126 logical
    volumes and no measurable memory. Both copper layers are gas-filled
    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
2026-08-07 Add Stage B, fix the aim point in both polar coordinates, self-contained Garfield
    Stage B (P0.9). stage_b/ turns Stage A ionization clusters into per-pad
    charge and time: drift depth from the recorded frame -> attachment -> drift
    time -> longitudinal and transverse diffusion -> mesh transparency -> Polya
    gain -> polar pad lookup -> per-pad charge and earliest arrival, written as a
    PadHitTree plus a StageBMeta tree carrying every assumption the run was made
    under. 16 closed-form self-tests run without Geant4, so a Magboltz table is a
    genuine drop-in: TransportTable is the only interface to implement.
    First result: 1.070 pads/event in Ar/iso (373 single / 26 double / 1 triple,
    400 muons, 3 mm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
2026-08-08 MX17 handoff: grounded inter-pad gaps cost 27%, warn P0.17 before it inherits the mistake
    MX17's V6 check (2026-08-08) measured the error of clamping the inter-pad
    gaps to ground at +27.2% on prompt capture plus a spurious 4.5x sub-pad
    amplitude modulation, refuting everyone's percent-level estimate. The
    adopted P0.17 route (ComponentParallelPlate::AddPixel) assumes exactly
    that grounded continuous plane, so record the trap and the cheap
    gerber-based check before the induction upgrade is built on it.
2026-08-08 P0.17: check P2's pad-gap fraction against the MX17 warning — 2.1 %, route stands
    MX17's audit session flagged (§2.6, cd5cc7d) that their weighting solver
    grounded the inter-pad gaps, and that this is not the percent-level error
    everyone assumed: +27.2 % on prompt captured charge, plus a spurious 4.5x
    sub-pad amplitude swing, and it is a DC error that does not decay with
    distance from the pad plane. It bites P0.17 specifically because the adopted
    route -- Riegler closed-form / ComponentParallelPlate::AddPixel -- assumes the
    anode is a continuous conductor of which the pad is a patch, i.e. exactly the
    grounded-gap model.
    Ran the cheap check §2.6 asks for, over all 42 rings of the gerber-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
2026-08-24 Make the exploded 3D views presentable for slides
    The exploded render was built to check the model, not to show it. Two
    changes for talks:
    p2_3d_exploded.png axes off, so the stack floats; labels moved onto
    leader lines that land on each piece
    p2_3d_exploded_lr.png new — the same model rolled 90 deg so the stack
    reads left to right, front window (beam side)
    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
2026-10-03 Add analytic study of low-energy photons from e- crossing the Al chapeau
    Brems (primary + delta-ray) yield vs photon energy for 119-144 MeV
    electrons through an Al wall, with a freestanding-plate thickness estimate.
2026-10-06 Build the P2 envelope from the design files; add the pillars
    Gas frame from DRIFT_P2_261124/FRAME_4mm/P2_Frame_V2.0.stp, sectioned
    exactly in FreeCAD (scripts/model/section_frame_step.py): 8 mm body,
    opening steps out 3 mm at the drift-foil ledge 4.0 mm above the board,
    so the frame is now two rings and the drift gas / mesh / amp gap use the
    board-side opening (r 110-600) and the front gas / foil / windows the
    window-side one (r 107-603, edges +3).
    Stack per Alexandra (2026-10-06): drift gap 4.0 mm, front gas 3.879 mm,
    one 120 um mylar + 1 um Al drift foil (two-foil model kept behind
    p2_cath_gap_mm > 0), mesh 45/18 um, amp gap 150 um, 10 um outer windows,
    10 mm sag both sides, 1 mm carbon b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
2026-10-06 Frame on the bulk Dynamask, carbon back frame to the pad zone, P2Sim stack comparison
    - Frame (P2_Frame_V2.0.stp) now stands on the 150 um bulk Dynamask, with the
    mesh cut inside it: board-side ring is exactly 4.000 mm, drift gas 3.964 mm.
    - New BulkDynamask ring under the frame.
    - Carbon back frame spans the board outline minus the pad zone. Back gas and
    back window use the pad-zone outline (P2Wedge.hh kZone*).
    - Gas table: ArIso9010 and NeIso8515 (experiment candidates). NeIso and
    ArCF4Iso flagged as campaign/test-beam gases.
    - scripts/model/compare_stacks_p2sim.py reads P2Sim MMP2_v4 and compares it
    layer by layer with ours (docs/figures/p2_stack_vs_p2sim.png).
    - Docs: SPS beam-te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
2026-10-07 submit_condor_p2: add the rnd2026 scan (gain recovery + e/gamma), update defaults; meeting slides
    --scan rnd2026: Ar/iso 95/5, 90/10 and Ne/iso 95/5, 85/15 at 3.964 and 5 mm
    drift gas; photons 10-150 keV; 100 MeV electrons at 0/20/40 deg; 150 GeV
    muons in the two SPS gases. Default drift 3.964 mm, muons 150 GeV.
    Claude-Session: https://claude.ai/code/session_01WPovVsCeC6juTNqN3UxcxX
2026-10-07 rnd2026 first analysis; fix soft-primary fluorescence label
    EventAction: a beam photon is born in the World volume, which the
    fluorescence rule counted as a solid, so a < 20 keV beam photon absorbed in
    the gas was labelled fluorescence-reabs. Exclude the World. Physics output
    unaffected; the analysis splits gas vs wall on convVolume.
    scripts/analysis/rnd2026_photons_electrons.py: P(>=1 primary) per photon,
    drift-gas deposit spectra vs 100 MeV electrons, upper cut, fold with the
    P2Sim flux. Results in docs/results/rnd2026.
    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
    [electron_summary.csv, fold_p2sim.csv, photon_summary.csv]
2026-10-08 Stage B: Magboltz gas transport (P0.10)
    Dry Magboltz tables for the six October-2026 gases, sampled to
    stage_b/gas_tables/magboltz_dry_20261008.json by export_gas_json.C, so
    Stage B needs no Garfield. MagboltzTable interpolates log-log at the drift
    field and is the default (--transport magboltz, --drift-field, default
    625 V/cm = SPS July 2026). StageBMeta records the field, sigma_L/T and the
    attachment length. 7 new self-tests (23 total, all pass).
    End to end on the 150 GeV SPS muons: v_d 44.8 um/ns Ar/CO2/iso (placeholder
    46.2), 106.4 um/ns Ar/CF4/iso (placeholder 50.0); latest first arrivals
    79 / 32 ns against 88 / 37 ns full-gap drift.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
2026-10-09 COMSOL mesh unit cell for P2: batch solve on lxplus, Garfield exports
    Re-solves a colleague's woven-mesh cell with the measured P2 mesh (pitch
    68 um, wire 18 um), 150 um gap and the SPS voltages (pads 0, mesh -450 V,
    625 V/cm drift) for 4 mm and 2 mm cells, via COMSOL 6.4 on CVMFS with the
    CERN licence, as an HTCondor job. Writes mesh.mphtxt + potential.txt for
    Garfield ComponentComsol to EOS.
2026-10-13 Mesh field map and transparency from the COMSOL cell; logbook source
    Garfield++ (pinned 927e5c21) reads the COMSOL unit cell, exports side/top
    field maps and field lines, and tracks electrons microscopically through the
    woven mesh (HTCondor, 6 gases x 2 cells). Transparency: Ar/iso 95/5 90.6 %,
    90/10 98.7 %, Ne/iso 95/5 93.2 %, 85/15 99.9 %, SPS gases 95-96 %; field
    lines alone 100 %; 2 mm and 4 mm cells agree. Figures and table in
    docs/results/mesh. Adds the logbook deck source (docs/logbook) with the new
    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
2026-10-13 Mesh transparency: review, drift sweep, literature validation
    Follows a review of the first transparency numbers:
    - Garfield: enable interface crossings for the field map, with a local
    patch for periodic maps (InterfacePanels::CrossedFolded tested steps
    across the cell face along a chord through the whole cell); track
    with null-collision steps (default free flights mis-track hot
    electrons near the wires: Ar/iso 95/5 90.6 -> 96.1 %); record why each
    electron stopped (wire / attachment / other); top of volume 1 mm up;
    mesh position detected from the map.
    - Geometry: the colleague's meshHeight is the wire centre plane; re-solve
    with the mesh bottom on the 150 um pillars (E_amp 28.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
2026-10-14 Validation checks: gap scan, Heed vs Geant4, near-mesh ionization, pillars, gas map, SPS drift scan; contamination study set up
    - Drift-gap scan 4-8 mm at 250 V above the mesh (COMSOL per gap ->
    Garfield, HTCondor DAG gaps.dag, make_gaps.sh): 95/5 mixes 94 -> 98 ->
    99.4 % at 4/5/6 mm. mesh_cell.sub takes the class via $(cls:default) so
    DAG VARS work.
    - Heed vs Geant4 primary ionization (heed_mip.cc, 100 MeV e-, 150 GeV mu):
    neon agrees at the peak, Geant4 argon peak 30-50 % higher.
    - Ionization within 100 um of the mesh in Geant4 photon events: 2-5 %
    for >= 30 keV, 15-44 % for <= 20 keV photons converting in the mesh.
    - Pillars: Geant4 map = V1 (det1-4) and CERN (det5) masks exactl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
2026-10-14 Geometry study: gain along drift lines (Penning), mesh/gap variation DAG
    mesh_gain.cc integrates alpha along RKF lines in the COMSOL cell (table only
    above 15 kV/cm: the 3-15 kV/cm grid gap gives garbage alpha). COMSOL template
    takes the wire radius; transparency takes the cell size from the elementary
    cell. make_geom_dag.sh: gap 120/135/165, wire 16/20, spacing 66/73, mesh 415 V,
    and 430/470 V cells for the gain slope.
    Claude-Session: https://claude.ai/code/session_01SqryNGtkNaGjzXj2VdN5C2
2026-10-14 DREAM charge calibration (200 fC range, ~18 ADC/fC) and measured absolute gain
    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
2026-10-14 COMSOL jobs fail on licence errors; geometry DAG throttled (2 solves), retried, resumable
    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
2026-10-14 Gain results of the geometry DAG (all gaps/voltages/variations, Penning r 0-0.7)
    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
2026-10-15 Contamination fit of the SPS drift scan: O2-equivalent attachment x T x shaping
    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
2026-10-15 Geometry: all mylar sheets ~50 um (outer windows 10->50, drift foil 120->50; front gas 3.949 mm)
    Alexandra 2026-10-15: all the mylar thicknesses are ~50 um.
    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
2026-10-15 Drift foil 50 um including its Al (49 mylar + 1 Al); front gas 3.950 mm
    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
2026-10-16 Heed vs Geant4 like-for-like: slab mode, PAI in the gas, PIXE switch
    Answers Dylan's MX17 handoff (2026-10-15). New mm_sim options, all off by
    default so production physics is unchanged:
    -m slab bare drift-gas box in vacuum, the Geant4 twin of heed_mip.cc
    --pai config G4PAIModel in region P2GasPAI (DriftGas + AmpGas, own cuts)
    --pai params same via G4EmParameters::AddPAIModel (works on 11.2.1)
    --gas-step max step in the gas (default 100 um, <= 0 = none)
    --no-pixe switch off PIXE
    ClusterTree gains birthVolume (where the ionising track was born).
    Results (docs/results/heed/pai): on the bare slab Geant4 PAI = Heed to 1 %
    (39.6/29 vs 39.9/29). PIXE (on in our list)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
2026-10-16 Validation step 1: SPS hit times vs Magboltz drift velocity
    sps_hit_times_extract.py (lxplus, EOS combined hits, drift_mesh_scan_1) and
    a toy DREAM forward model (sps_drift_velocity_check.py). Agrees at
    >= 625 V/cm; data slower at 250-500 V/cm and early at 125 V/cm.
    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
2026-10-16 Geant4 + Garfield++/Heed coupling for the drift-gas ionization (--heed)
    HeedGasModel: a G4VFastSimulationModel on region P2HeedGas (DriftGas).
    Charged tracks above threshold (e+- 1 MeV, mu 10, pi 20, p 90 MeV) are
    handed to TrackHeed along a straight line to the gas exit; every Heed
    electron becomes one ClusterTree entry (nPrimary = 1, own x/y/z/t), so
    Stage B is unchanged. The particle continues in Geant4 from the exit with
    the Heed energy loss subtracted. Softer tracks stay in Geant4 (edep/W).
    Heed sees a +-10 cm box around the entry with a 1 um z margin: the full
    P2 wedge, and a start point a rounding error outside the gas, both made
    Heed return no clusters. Single-thread only.
    Built aga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
2026-10-16 Logbook: Heed coupled into Geant4 (slide heedcouple)
    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
2026-11-01 Feynman validated: Geant4 (KS p=0.49) and Garfield (lxplus vs Feynman 20 seeds: 0.9341 vs 0.9345); memory and statistics guidance
    - Garfield transparency/gain needs ~3 GB per process (measured): recipes use
    --mem-per-cpu=4000; slurm_array default stays 2 GB (Geant4)
    - published Ar/iso 625 V/cm T=0.943 was a 2-sigma-high single 3000-e run;
    20k-electron rerun 0.934 +- 0.002 (recorded in OPEN_PROBLEMS, HANDOVER)
2026-11-01 Route the drift-gap/gas question through the timing toy (vmm/time_resolution.py) with validated inputs (OPEN_PROBLEMS §2 item 5a); Stage B -> VMM becomes the later complete check (5b)
    Toy checked: runs, --gap works; noted its gas names/missing rnd2026 gases and
    the 3 mm placeholders as housekeeping for the student.
2026-11-01 vmm/README §6b: SPS July 2026 VMM operating point as run (gain, peaking, per-chip sdt, baselines, DAC->mV->ADC->fC), with sources; linked from OPEN_PROBLEMS 5a
